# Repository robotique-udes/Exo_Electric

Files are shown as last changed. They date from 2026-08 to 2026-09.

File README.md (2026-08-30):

# Description
Ce répertoire regroupe les différents PCB de l'exosquelette au fil des compétitions. Il vise aussi à standardiser la création des schémas électriques ainsi que des PCB afin de les rendre plus lisibles et plus faciles à réviser et consulter. Les PCB avant 2026 ne suivent pas nécessairement le standard.

# Structure du repo
```
main
├── ACE2027/
│   ├── README.md
│   ├── Schéma-bloc
│   └── PCB1/
│       ├── README.md
│       ├── Schéma-bloc
│       │   ├── V1_0/
│       │   │   └── Fichiers KiCad
│       │   ├── V1_1/
│       │   │   ├── README.md
│       │   │   └── Fichiers KiCad
│       │   └── V2_0/
│       │       ├── README.md
│       │       └── Fichiers KiCad
│       └── PCB2/
│           └── (Même structure que PCB1)
└── ACE2028
    └── (Même structure que ACE 2027)
```
- Un dossier est créé pour chaque année de compétition
    - Contient un README.md décrivant le fonctionnement global du système électrique et présentant le schéma-bloc
    - Contient le schéma-bloc en image et dans son format original décrivant l'interaction entre les sous-systèmes électriques
    - Un dossier est créé par PCB
        - Contient un README.md qui explique le fonctionnement du PCB, contient les calculs et hypothèse fait pour le pcb et présente le schéma-bloc. Le README.md doit dire où se trouve le contour du pcb s'il a été fait sur ONSHAPE
        - Contient le schéma-bloc en image et dans son format original décrivant l'interaction entre les modules du PCB
            - Un dossier est fait pour chaque version du PCB.
                - La version 1_0 n'a pas besoin de README, mais les versions subséquentes devront en avoir un qui décrit les changements par rapport à la version antérieure.
                - Contient tous les fichiers KiCad

# Branches
Une branche est créée pour chaque PCB. <br>
Cette branche doit contenir le nom du PCB ainsi que sa version et le déroulement de la vie de cette branche se déroule ainsi:
1. Si le pcb est particuliairement complexe, écrire le readme et le shéma bloc qui défini ce que le PCB fait et comment il va le faire
2. Création d'une pull request vers le main afin de faire validé le fonctionnement du PCB
    - Faire les correctifs et demander à nouveau la vérification
3. Création du schéma électrique
4. Création d'une pull request vers le main afin de faire vérifier le schéma
    - Faire les correctifs et demander à nouveau la vérification
5. Création du PCB
6. Création d'une pull request vers le main afin de faire vérifier le PCB
    - Faire les correctifs et demander à nouveau la vérification
7. Suppression de la branche une fois le PCB commandé

## Convention de versions:
- V1.0  Premier prototype
- V1.X  Corrections mineures qui ne demandent pas de recommander le PCB
- VX.0  Révision majeure qui demande de recommander le PCB
- Chaque révision doit être documentée dans le README avec une explication claire des changements par rapport à la version précédente.

# Autres
**Il est très important de sauvegarder les fichiers et de fermer KiCad avant chaque commit**

# Standards à respecter
Les standards pour le schéma électrique se trouvent [ici](guideSchema.md) <br>
Les standards pour le PCB se trouvent [ici](guidePCB.md) <br>
Ces standards doivent être consultés et compris avant d'entamer le travail sur un schéma ou sur un PCB

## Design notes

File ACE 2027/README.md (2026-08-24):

# ACE 2027

Projet d’électronique et de communication pour l’exosquelette électrique.

> **Objectif principal** : faire communiquer les différents modules de l’exosquelette via un bus CAN fiable, tout en distribuant l’alimentation et en assurant les fonctions de sécurité. Le tout en prennant moins d'espace qu'avant.

## Sommaire

- [Architecture](#architecture)
- [Modules](#modules)
- [Communication](#communication)
- [Documentation du dépôt](#documentation-du-dépôt)
- [À documenter](#à-documenter)

## Architecture

Le système est organisé autour d’une carte mère (**MoBo**, *Motherboard*) qui coordonne les modules. Le **BMS** supervise les batteries et la sécurité. Les **BIMU** mesurent les mouvements, tandis que les cartes d’interface des moteurs assurent leur raccordement au réseau.

## Modules

| Module | Rôle | Éléments principaux |
| --- | --- | --- |
| **MoBo** | Carte mère et coordination de l’exosquelette | ESP32, conversion 5 V vers 3,3 V, filtrage de tension, connecteurs |
| **BMS** | Gestion des batteries et fonctions de sécurité | Fusibles, arrêt d’urgence, suivi de l’état des batteries |
| **BIMU** | Mesure et prétraitement des mouvements | IMU, traitement local des données, transmission via CAN |
| **Moteur** | Raccordement des moteurs au réseau | Carte d’interface, chaînage (*daisy chain*), connecteurs de type Ethernet |

### MoBo

La MoBo est la carte mère de l’exosquelette. Elle contient l’ESP32, qui coordonne le système, ainsi qu’une conversion 5 V vers 3,3 V, le filtrage des tensions et les connecteurs nécessaires.

### BMS

Le BMS gère les batteries, les fusibles et l’arrêt d’urgence. Il doit également communiquer avec la MoBo afin de transmettre l’état des batteries.

### BIMU

Chaque BIMU effectue localement le traitement initial des données de son ou de ses capteurs IMU, puis transmet les données préparées sur le bus CAN.

### Moteurs

Une carte d’interface est placée au niveau des moteurs. Elle facilite le chaînage des câbles et permet l’utilisation de câbles Ethernet pour le raccordement physique.

## Communication

Les modules communiquent principalement sur un bus CAN transporté par des câbles Ethernet. Le branchement général est représenté ci-dessous.

Schéma général du réseau de l’exosquelette

Détail du raccordement des modules

La liaison entre la MoBo et le BMS est particulière : elle doit fournir davantage de courant que les autres liaisons. Son raccordement est présenté ci-dessous.

Liaison entre la MoBo et le BMS

### Règles CAN à définir

Les éléments suivants doivent être précisés pour rendre l’architecture exploitable par toute l’équipe :

- débit du bus CAN et longueur maximale des câbles ;
- brochage des connecteurs et câblage exact de l’alimentation ;
- identifiants CAN attribués à chaque module ;
- format des messages, périodicité et unités des mesures ;
- terminaison du bus et emplacement des résistances ;
- comportement attendu en cas de perte de communication ou d’arrêt d’urgence.

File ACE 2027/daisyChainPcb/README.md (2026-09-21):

# PCB daisy chain

Ce PCB permet de passer les alimentations et les signaux de l'exo à travers celui-ci à la chaîne afin d'éviter les câbles superflus. Il sera sur les moteurs et permettra en même temps la communication et l'alimenation de ceux-ci.

## Objectifs
- Passer l'alimentation 48V d'un côté du PCB à l'autre
- Alimenter les moteurs
- Passer l'alimentation 5V d'un côté du PCB à l'autre
- Alimenter une puce permettant la conversion du 5V au 3.3V pour la communication I2C
- Remettre à niveau le signal I2C afin de s'assurer de sa bonne transmission
- Le rendre compatible avec l'exo 2026 et 2027
    - Être capable de passer la communication CAN tout en gardant la communication I2C au cas où elle doit être utilisé
- Se monter sur les moteurs de facon compacte et fiable
- Transmettre le signal UART (RX/TX) afin de communiquer de cette méthode avec les moteurs si c'est nécessaire (Certaines données peuvent être récuperer seulement dans un mode de communication et non l'autre)

## Conception

### Alimentation
Ce PCB doit gérer à la fois une alimentation de 48V et de 5V. Il y a deux grounds séparé. Le premier est celui de l'alimentation 48V et le deuxième est celui de l'alimentation de 5V. Le PCB a deux ground planes qui sont associés avec l'alimentation 5V. Cette décision a été prise afin de s'assurer de l'intégrité des signaux en donnant la plus grande surface de ground pour le circuit qui transporte les signaux. Ainsi, le ground lié à l'alimentation 48V est seulement connecté par des traces normales. La séparation de ces deux grounds permet aussi de s'assurer de ne pas avoir de tensions parasites qui passent par les IMU ou autre processeurs plus sensibles et évite donc de les détruire.

La communication I2C se fait à une tension de 3.3V. Il y a donc, sur le PCB, un convertisseur DC/DC qui transforme la tension de 5V vers 3.3V. Cette tension est ensuite envoyé vers les signaux I2C à travers une résistance de 1k.

### Disposition du PCB et choix de conception
Le PCB s'attache aux moteurs du côté des connecteurs de ce dernier. Il est donc important qu'il soit assez petit pour ne pas gêner aux mouvements de l'utilisateur. C'est pourquoi il n'y a pas de connecteurs pour l'alimentation et les signaux du côté du PCB. Seulement des beignes sont présents afin de souder des fils qui, eux, auront un connecteur au bout afin de se connecter aux moteurs.

Nous avons deux ground planes pour l'alimentation de 5V qui ont pleins de vias afin de bien connecter les deux planes ensemble.

Les traces qui transmettent les signaux sont le plus près possible l'un de l'autre et ont les mêmes longeurs. L'utilisation des vias a aussi été évité le plus possible.

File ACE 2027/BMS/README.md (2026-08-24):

# BMS

Carte de gestion et de distribution de l'alimentation de l'exosquelette.

Le BMS doit gérer l'arrêt d'urgence, la protection des batteries, la sélection entre deux batteries et la distribution des rails **5 V** et **48 V**. Il transmet également l'état du système au MoBo.

> **État du projet :** conception préliminaire  \
> Plusieurs valeurs et choix de composants restent à valider avec les batteries et les charges réelles.

## Objectifs

* Géré l'arrêt d'urgence de l'exosquelette
* Intégré des fuses de sécurités(une par batterie, une par jambe, une pour le circuit 5V)
* Avoir un circuit contre la reverse polarity(back current EMF)
* Une stratégie de Handshake ou autre pour ne pas shorté les batteries ensembles(mosfet de controle)
* LED pour confirmé que le circuit est alimenté(après les fuses pour connaitre l'état des fuse en même temps)
* Pouvoir géré 4A à 48V continue
* Pouvoir delivré 2.5A à 5V continue (5*200mA par BIMU et 400 mA pour le MOBO, le reste est pour le BMS) 
* Pouvoir donner le pourcentage de batterie restante
* Avoir une connection XT ??? par batterie
* Avoir une conenction Ethernet pour la connection 5V et CAN
* Avoir une connection XT30 par jambe
* Pouvoir automatiquement changé de batterie
* Avoir des lumières d'état autour des batterie

## Conception

- Seuls les ESP32 du **MoBo** et du **BMS** disposent d'une connectivité sans fil. Les deux sont inclus dans le budget de puissance, mais seul le sans-fil du MoBo sera utilisé en fonctionnement normal. La consommation **MISC** représente une estimation des pertes du PCB, des pertes de conversion, des petits composants et des LED. **LED_BMS** correspond à la puissance disponible pour d'éventuelles LED décoratives. Elle ne fait pas partie du total et sera calculée lorsque les autres besoins seront figés.

### Budget de puissance 5 V

Les estimations ci-dessous utilisent le rail 3,3 V et une marge de conversion de 20 %.

| Charge | Hypothèse | Puissance estimée |
| --- | --- | ---: |
| MoBo | `(300 mA + 100 mA MISC) x 3,3 V` | **1,32 W** |
| BIMU | `(35 mA + 100 mA MISC) x 3,3 V` | **0,45 W** |
| BMS | `(300 mA + 100 mA MISC) x 3,3 V` | **1,32 W** + `LED_BMS` |

Un rendement de **80 %** est retenu pour le convertisseur principal vers 5 V. Cette hypothèse reste volontairement prudente, car la tension de batterie peut varier fortement et le convertisseur doit couvrir une grande plage de tension d'entrée.

### Estimation

```text
P nécessaire = (1,32 W + 0,45 W + 1,32 W) / 0,80
			 = 3,87 W

I sous 5 V  = 3,87 W / 5 V
			 = 0,774 A
```

Un convertisseur **5 V / 1 A** couvrirait donc l'estimation actuelle. Cependant, le câble Ethernet envisagé avec des conducteurs de **23 AWG** est donné pour environ **0,7 A par conducteur**. Avec trois conducteurs 5 V et trois conducteurs GND, la capacité théorique atteindrait `0,7 A x 3 = 2,1 A`.

Par prudence et pour conserver une marge d'évolution, le convertisseur cible sera choisi dans une plage de **2 à 4 A**, selon les besoins confirmés et les composants disponibles. Un fusible de **2 A** en amont du câble est envisagé.

## Points à confirmer

- Référence exacte des batteries, tension minimale et tension maximale.
- Type de connecteur batterie (`XT ?`) et courant admissible réel.
- Courant de démarrage et courant continu de chaque jambe.
- Méthode de mesure de l'état de charge et précision attendue.
- Protocole du handshake de sélection de batterie et comportement en cas de défaut.
- Validation thermique du convertisseur 5 V, des MOSFET et des fusibles.
- Courant admissible du câble Ethernet utilisé pour le 5 V sur la longueur finale.

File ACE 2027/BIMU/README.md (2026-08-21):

# BIMU — IMU ESP32 + LSM6DSV16BXTR

Petit module IMU conçu autour d'un `ESP32` et du capteur inertiel `LSM6DSV16BXTR`. Il fournit des mesures d'accélération et de rotation destinées aux calculs de l'exosquelette.

## Objectif
* Communication CAN avec le reste de l'exosquelette
* Refresh rate minimal de 100Hz si possible 200Hz pour futur proof
* Précision de 1° minimum
* Consommation minimale
* Programmation par USB
* 3 DEL pour diagnostic

## Conception
Le `LSM6DSV16BXTR` propose des modes d'échantillonnage configurables, du mode basse fréquence pour économiser l'énergie jusqu'à des ODR élevés (plusieurs centaines de Hz, voire le kHz en modes haute performance selon la fiche technique). Pour la plupart des usages, un réglage entre 200 et 1000 Hz constitue un bon compromis entre réactivité et consommation. Pour des dynamiques très rapides, privilégier `SPI` et activer les modes haute fréquence.

Après étalonnage (offsets, facteurs d'échelle, compensation thermique) et filtrage (filtre complémentaire, filtre de Kalman ou AHRS), on peut viser une précision d'orientation de l'ordre de 0,1° à quelques degrés selon les conditions, la durée d'intégration et la qualité mécanique du montage. Le bruit intrinsèque du capteur est typiquement de l'ordre de quelques µg/√Hz pour l'accéléromètre et quelques mdps/√Hz pour le gyroscope ; la performance finale dépendra du calibrage et du traitement logiciel.

Trois LED facilitent le diagnostic : la LED verte indique la présence de la tension 3,3 V, la LED bleue signale la connexion/heartbeat avec la carte principale, et la LED d'erreur (rouge) s'allume en cas de problème (communication avec le capteur, auto-test ou alimentation instable). Les motifs de clignotement sont configurables dans le firmware pour différencier les types d'anomalies.

Capture d’écran 2026-08-16 130516

Alimentation et connexions : entrée 5 V (par exemple fournie par l'Ethernet/PoE) avec régulation 3,3 V sur le PCB. Le capteur communique avec l'ESP32 par `SPI`. L'ESP32 communique avec le reste de l'exosquelette via `CAN`. La puce peut être programmée via `USB-C` ou `UART`. Il a bien sûr les boutons pour BOOT et EN l'ESP-32.

Capture d’écran 2026-08-16 130627

Les résistances de terminaison CAN sont présentes sur le PCB. Il est important de respecter le côté maître du bus si celui-ci est utilisé. Pour activer la terminaison, souder C210, R211 et R212.

Capture d’écran 2026-08-16 130715

À prévoir dans le firmware : une fonction d'étalonnage, une compensation en température, le traitement des données sur l'IMU et une synchronisation via heartbeat. Il faut garder à l'esprit que le PCB ne sera pas nécessairement installé dans l'orientation prévue ; prévoir donc un réglage d'axes dans le firmware.

Il est possible de short des broches pour connecter ou isoler l'UART provenant de l'Ethernet vers l'ESP32 (utile pour communiquer avec le moteur si nécessaire).

Capture d’écran 2026-08-16 130741Capture d’écran 2026-08-16 130730

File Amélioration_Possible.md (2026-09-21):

| Idée | État | Année intégration | Description |
| --- | --- | --- | --- |
| **BIMU** | En cours | ACE2027 | Faire un IMU custom qui peut être connecté par CAN |
| **BMS QUICK SWAP** | En cours | ACE2027 | Faire un BMS qui permet de quick swap des batteries de perceuse |
| **EMG CUSTOM** | En attente | ACE2027 | Faire des emg qui permettrais de quantifier l'efficacité de l'exosquelette et peut-être de le controlé dans une prochaine année |
| **BATTERIE CUSTOM** | En cours | ACE2028 | Faire notre propre batterie avec potentiellement un BMS custom |
| **LIGHT SHOW** | En attente | ACE2027 | Faire un module LED CAN  |
| **E** | En attente | ACE20?? | Faire  |

Mobo

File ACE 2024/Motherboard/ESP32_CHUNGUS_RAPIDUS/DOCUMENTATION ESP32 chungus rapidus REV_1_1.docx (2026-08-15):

UNIVERSITÉ DE SHERBROOKE

Faculté de génie

Département de génie électrique, génie informatique et génie robotique

Documentation
ESP32 CHUNGUS RAPIDUS REV. 1.1

Groupe technique Robotique UdeS

Biogénius

Présenté aux

Membres de l’équipe Biogénius, Contrôle

Présenté par

Jacob Turcotte – turj3113

Sherbrooke – 24 Mai 2024

Table des matières

Liste des figures

Liste des tableaux

Lexique

Terme technique | Définition

Liste des symboles

Symbole | Définition

Liste des acronymes

Acronyme | Définition

# 1. Introduction

Ce document a été conçu pour vous guider à travers les différentes étapes et composants de notre système, depuis l'identification des problèmes courants jusqu'aux pistes d'amélioration futures. Vous trouverez des sections détaillées sur la connexion des différents modules, l'alimentation, et l'utilisation de périphériques I2C tels que le multiplexeur, les extensions GPIO et PWM. Nous couvrirons également l'intégration du microcontrôleur ESP32, ainsi que les solutions d'affichage à LED. Chaque partie est structurée pour offrir une compréhension claire et pratique, facilitant ainsi la mise en œuvre et le dépannage.

# 2. Problèmes connus et solutions

## Liste de problèmes

- Alimentation 3v3 qui n’allume pas
  - Si nous allons voir la documentation des MIC5504-3.3YM5 (REF), à la page 9 (REF image). Il est expliqué que la pin ENABLE doit être à HIGH (tension plus haute que 1.2V). Bien qu’il ait une résistance pull-down, il est préférable de mettre ce pin à HIGH pour assurer le bon fonctionnement de l’alimentation.

Figure 1: Page 9 documentation MIC5504

  - La REV1.1 a un saut de soudure disponible sur chacun des MIC5504 mais celui -ci va à la terre (REF image). Ainsi, l’utilisation du saut de soudure ne règle en aucun cas le problème.

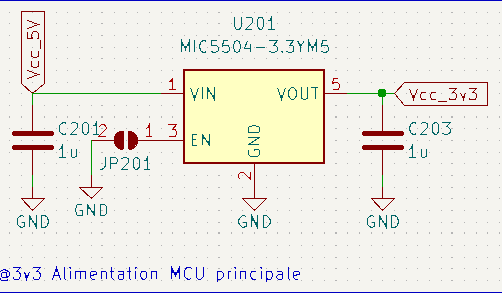
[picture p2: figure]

Figure 2: Démonstration du problème d'alimentation

- Sérigraphie à l’envers
  - La sérigraphie des connecteurs du côté gauche (connecteur pour le BNO de la hanche gauche et connecteur du MD gauche), sont tous les deux inversé de 180 degrés (REF image).

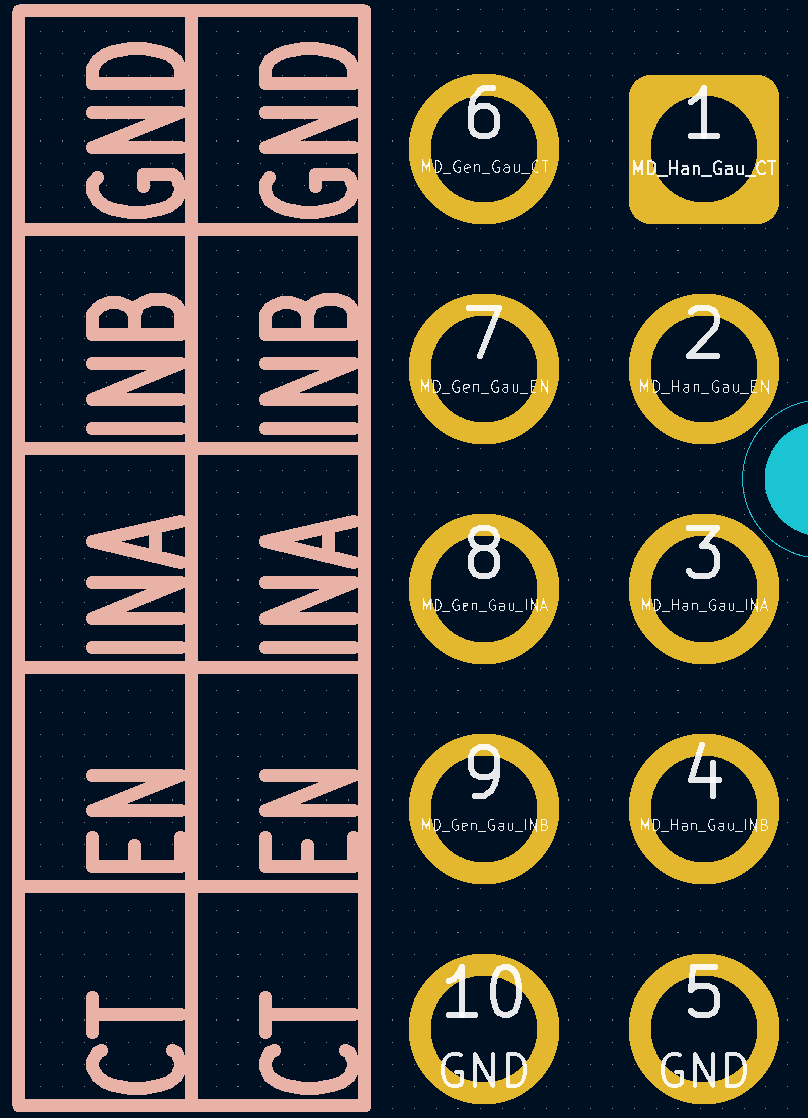
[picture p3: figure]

Figure 3: Démonstration de la mauvaise sérigraphie du connecteur pour MD gauche

- Manque le connecteur TTL pour le HMI
  - Le connecteur pour le HMI est manquant sur le PCB. Les pins à utiliser sont, GPIO17 et GPIO16. Il manque aussi les connections nécessaires pour alimenter le HMI.
- Reset des capteurs sur pin GPIO TX
  - La pin GPIO17 utilisée comme transmetteur (TX) afin de communiquer avec le HMI est déjà utilisé (REF image). Elle est connectée au signal Reset envoyé aux capteurs. Cela a été fait afin de pouvoir mettre le signal à LOW dans le code si jamais le MCU détecte une erreur venant des capteurs.

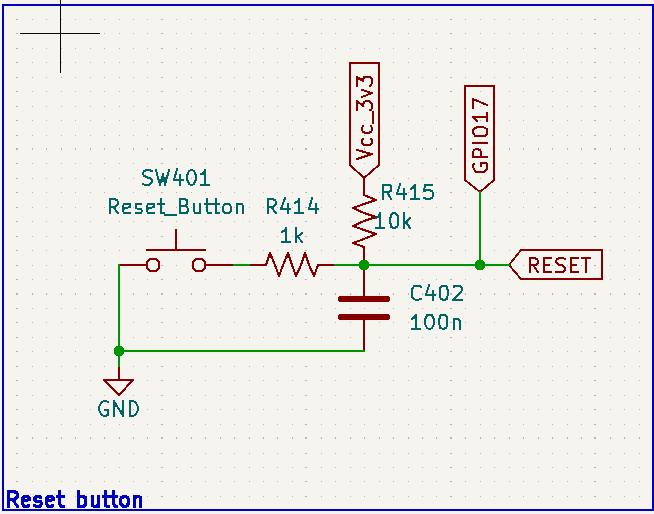
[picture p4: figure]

Figure 4: Démonstration de l'erreur RESET dans le schéma électrique

- Connection I2C sur le module PWM inversé
  - Les pins de la connexion I2C allant du MCU au PCA9685PW sont inversé. Le SDA du Esp32 est dans le SCL du module et le SCL du MCU est dans le SDA du PCA9685PW.
- PULLUP Nécessaire sur la moustache
  - Les proxims sont trop éloignés et le SCL n’a pas le temps de revenir à 3v3. Le fix est d’ajouter une PULLUP 2k sur la moustache car en ce moment c’est la pullup du BNO qui s’en occupe qui est à genre 3m.

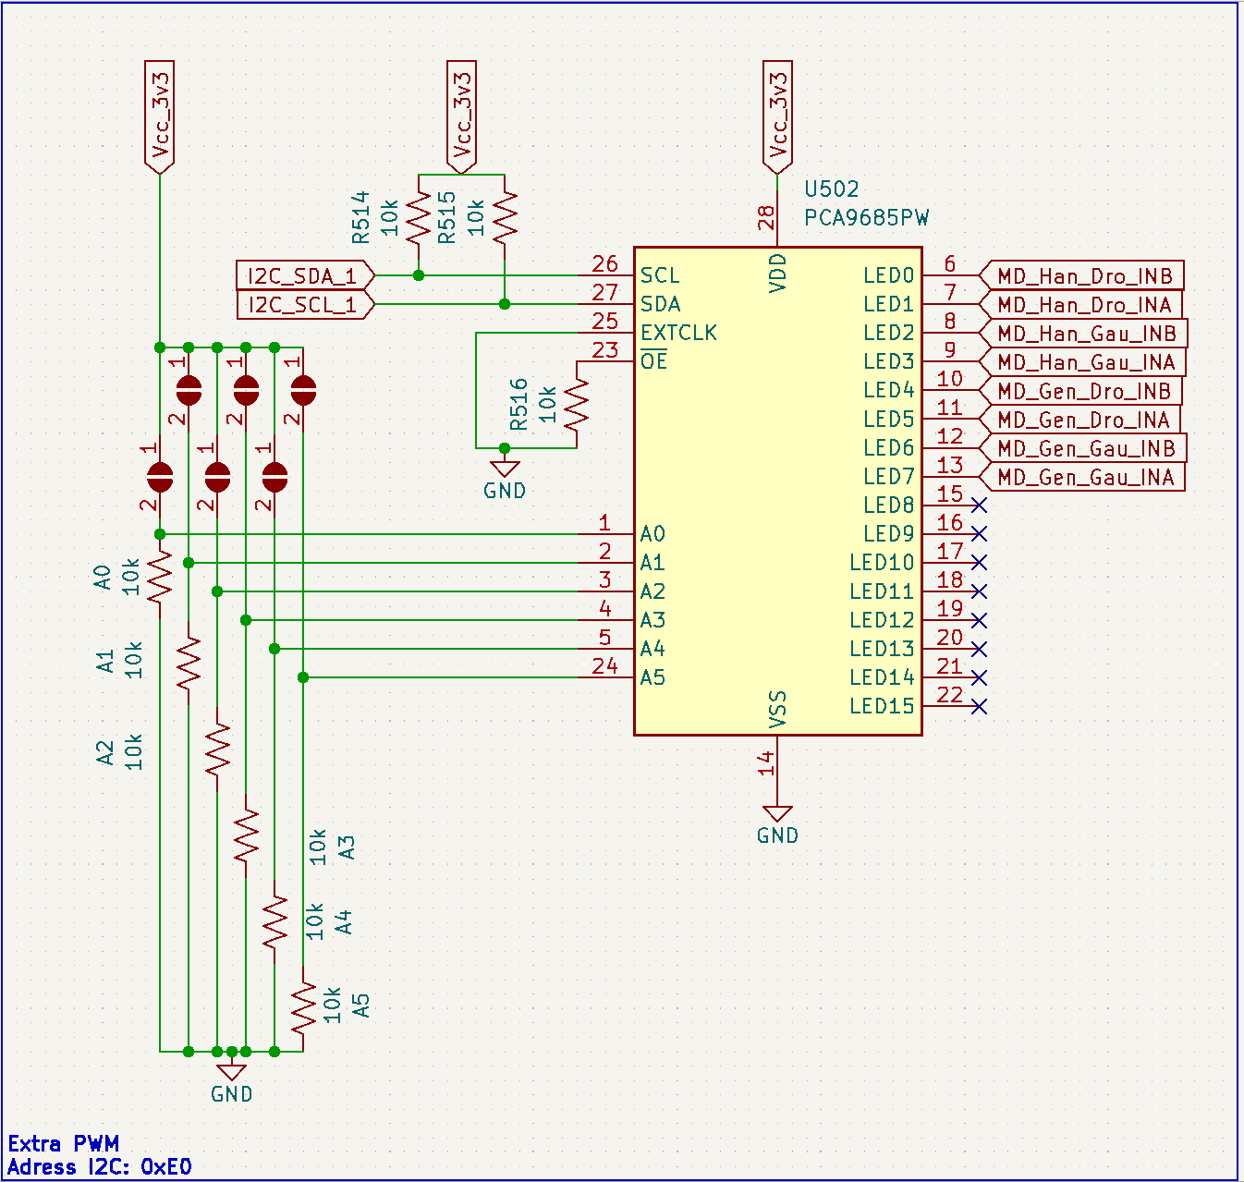
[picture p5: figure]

Figure 5: Démonstration du schéma électrique avec erreur I2C

- Connecteur du relais et du BNO dos sont trop proche
  - Les deux connecteurs sont beaucoup trop proches de l’un et l’autre. Dès que l’on branche les fils dessus, il n’est pas possible de brancher l’autre sans que celui-ci soit incliné (REF image).

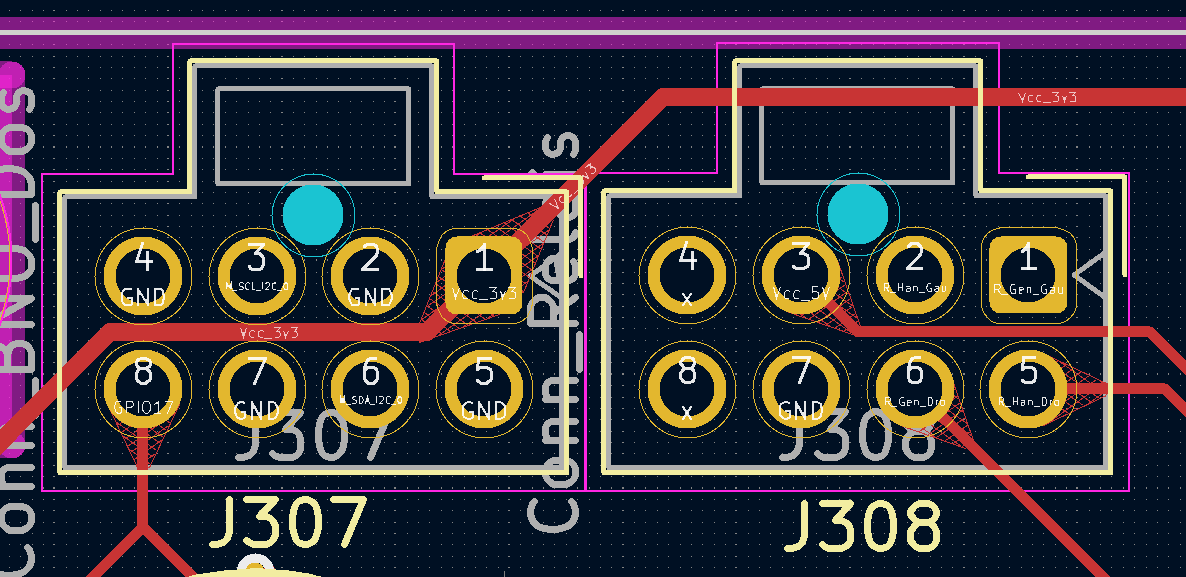
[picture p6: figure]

Figure 6: Démonstration dans le PCB editor des connecteurs trop proches

- BNO dos fait tout planter
  - Lorsque branché au PCB principale, le BNO dos fait tout planter. La communication I2C ne marche plus et aucun autre BNO est détecté.
- Pas capable de télécharger du code dans le ESP32
  - La pin GPIO12 doit être à LOW lorsque nous téléchargeons du code dans le ESP32. La pin en question est branché à l’encodeur du moteur genou droit, il se peut que la pin soit à HIGH à certains moments.

## Liste de solutions temporaires faits

- Alimentation 3v3
  - Nous avons utilisé un fil de cuivre émaillé de 4oz afin de souder les pins ENABLE au 5V entrant (REF image).

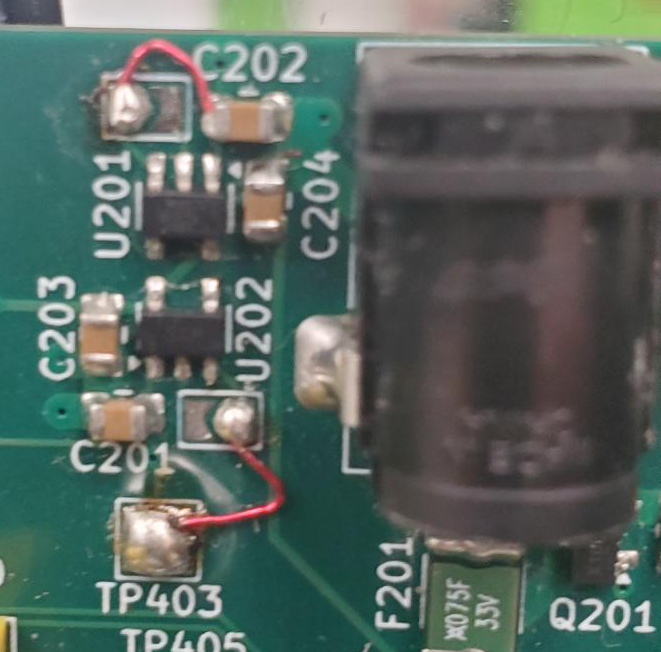
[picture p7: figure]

Figure 7: Démonstration de la solution temporaire de l'alimentation

- Sérigraphie
  - Nous avons utilisé un marqueur noir afin d’effacer la mauvaise sérigraphie et de réécrire le bon brochage (REF image).

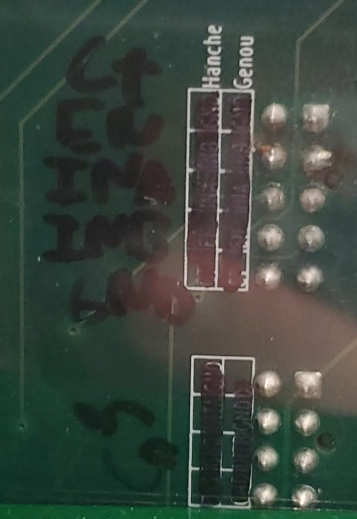
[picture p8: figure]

Figure 8: Démonstration de la sérigraphie temporaire

- Connecteur HMI
  - Nous avons soudé un connecteur Molex nano fit 2 par 2 sur les pins GPIO17 (TX), GPIO16 (RX) et nous avons utiliser les points de tests 5V et GND afin d’alimenter le HMI (REF image).

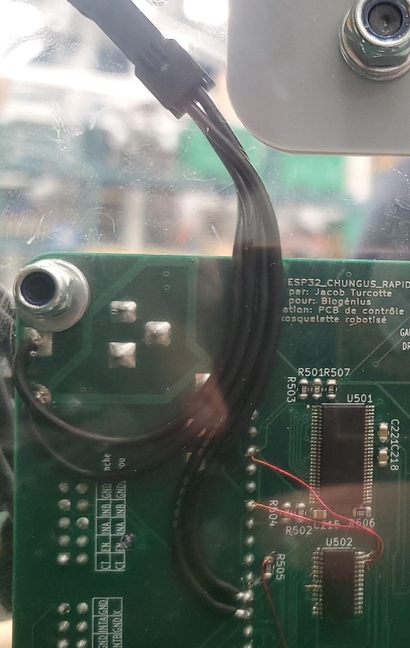
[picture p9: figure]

Figure 9: Démonstration du connecteur 2 par 2 HMI

- GPIO17
  - Nous avons gratté chaque trace RESET allant au GPIO17. Il a ensuite été nécessaire de reconnecter toutes ces traces ensemble afin de s’assurer du bon fonctionnement du bouton RESET. Nous avons utilisé un fil de cuivre émaillé de 4oz afin d’y arriver (REF image).

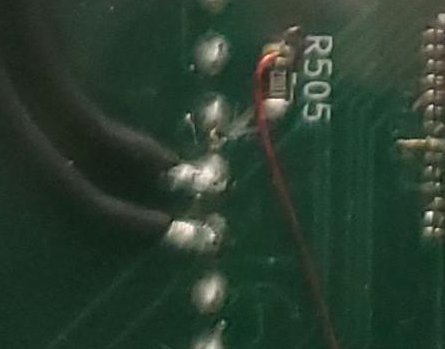
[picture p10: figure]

Figure 10: Démonstration du fixe du GPIO17

- I2C Module PWM
  - Nous avons dessoudé les pins I2C du module et nous les avons resouder correctement avec l’aide de fils de cuivre émaillé 4oz (REF image).

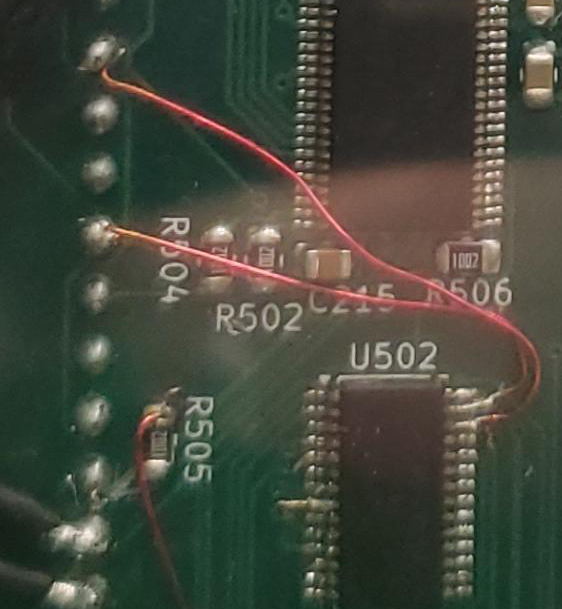
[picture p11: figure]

Figure 11: Démonstration de la reconnexion du port I2C au module PWM

- Connecteur relais et connecteur BNO dos
  - Nous avons sablé l’un des 2 connecteurs afin de laisser assez de place pour l’autre (REF image).

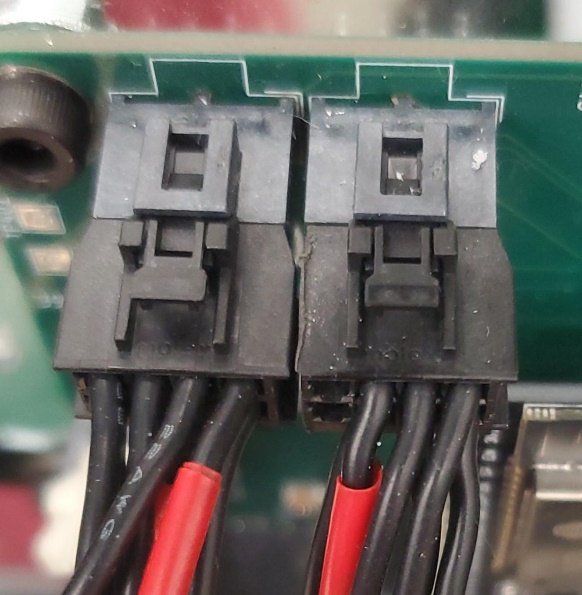
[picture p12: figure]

Figure 12: Démonstration des connecteur BNO dos et relais

- BNO dos
  - Le problème ne vient pas du PCB CHUNGUS RAPIDUS, il vient du boitier créer afin de protéger le BNO. L’une des 2 vis rattachant le boitier au frame était trop haute et causait un court-circuit entre le GND, RESET, SDA et SCL. Le fix a été de rajouter des rondelles afin d’augmenter la distance du PCB BNO et l’enveloppe. Nous avons aussi changé la vis M6 pour une vis M3.
- Télécharger du code dans le EPS32
  - La solution temporaire est simplement de faire tourner le moteur genou droit jusqu’à temps que celui-ci soit un niveau LOW.
- PULLUP nécessaire pour les moustaches
  - Nous avons soudé une 2k entre SDA et 3v3 puis SCL et 3v3. Nos signaux sont beaux à nouveau

# 3. Liste des connections

## Connections vers capteurs ou actuateurs (REF image)

- Une connexion BNO dos 2 par 4 (rouge)
- Une connexion relais 2 par 4 (vert)
- Deux connexions « Motor Drive » 2 par 5 (jaune)
- Deux connexions pour les encodeurs des hanches (bleu)
- Deux connexions aux moustaches 2 par 8 (mauve)

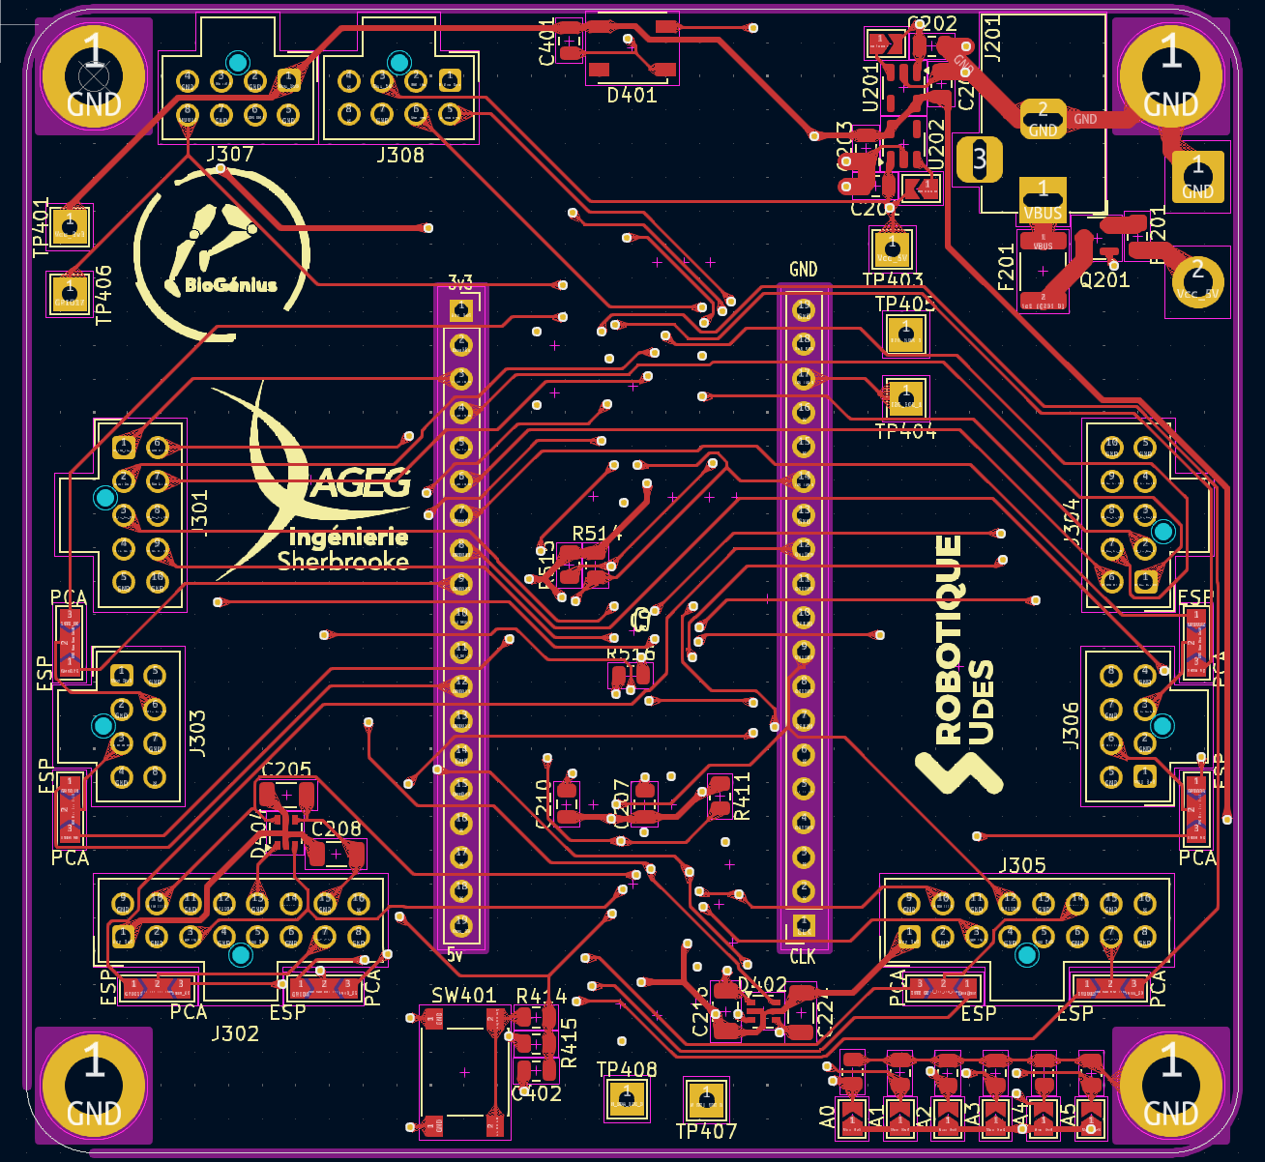
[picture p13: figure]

Figure 13: Connections capteurs/actuateurs

## Connections pour ESP32

- Se référer à la section (REF section ESP32) pour plus de détails sur le pin out. (Jaune)

Figure 14: Connexion ESP32

## Connections pour alimentation

- Il a deux façons d’alimenter le PCB
  - La première en rouge, est d’utiliser le connecteur « Barrel jack »
  - La deuxième en jaune, est de souder le GND au trou carré et le 5V au trou rond.

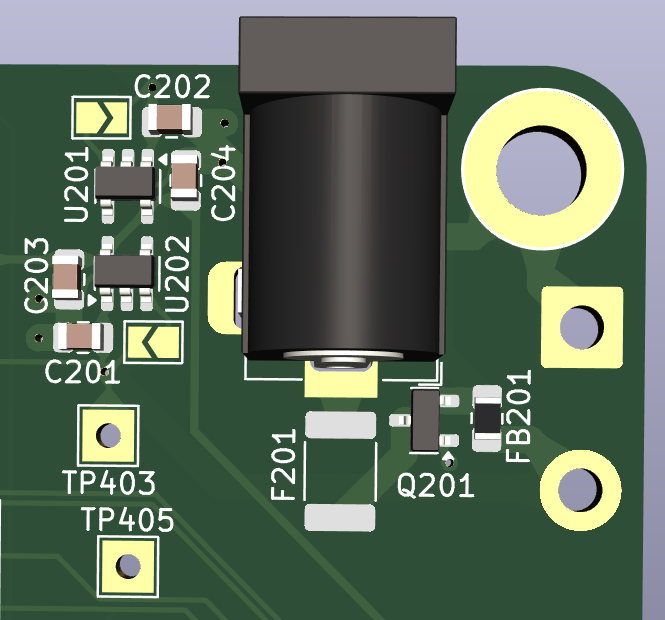
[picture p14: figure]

Figure 15: Connections alimentation

# 4. Alimentation

Il a 3 alimentation externes possible au circuit « Chungus rapidus ». Il a celle USB venant du ESP32, le « Barrel jack » et les fils que nous pouvons souder. Chacune de ces alimentations sont 5V.

Il a au total, 3 régulateurs de tension sur le circuit. Deux MIC5504-3.3YM5-TR (régulateur 3v3) et un régulateur 3v3 sur le ESP32 (AMS1117-3.3). Au total, le circuit peut alimenter 1,6A à 3v3 ce qui est plus que suffisant pour alimenter tout les circuits et capteurs (environs 750mA total).

# 5. TCA9548 (Multiplexeur I2C)

L’adresse I2C du multiplexeur est le 0x70. Le multiplexeur permet de rediriger la communication I2C d’un port vers 8 autres ports I2C. Nous avions un problème d’adresse où les BNO ont juste 2 adresses possibles. Avec 5 BNO sur l’exosquelette, on avait des erreurs de communication tout le temps. Le TCA8548 vient régler se problème. Nous utilisons présentement seulement 3 des 8 ports I2C disponibles.

Voir I 2C-scanner dans le GitHub pour plus d’information.

# 6. PCA9685 (PWM)

L’adresse I2C du PCA9685 est le 0x7C. Il permet de diminuer les pins utilisés du ESP32 et d’alléger le code. Les PWM sont utilisés afin de contrôler la vitesse et la puissance des moteurs. Au total, nous utilisons 8 des 16 pins PWM disponible sur le PCA9685.
L’adresse de celui-ci peut être changé au besoin en soudant les ponts d’étain.

Voir ESP-Motor dans le GitHub pour plus d’information.

# 7. PCA9505 (GPIO)

L’adresse I2C du PCA9505 est le 0x20. Il permet aussi de diminuer les pins utilisés du ESP32. Cependant celui-ci n’allège pas le code. Le PCA9505 est un « GPIO extender », il rajoute 40 pins GPIO à un circuit. Dans notre cas nous utilisons seulement les pins comme sortie car le protocole I2C n’est pas assez rapide pour gérer les encodeurs.
Sur les 40 pins, 17 sont utilisées. L’adresse de celui-ci peut aussi être changé au besoin.

Voir Pin_extender dans le GitHub pour plus d’information.

# 8. ESP32

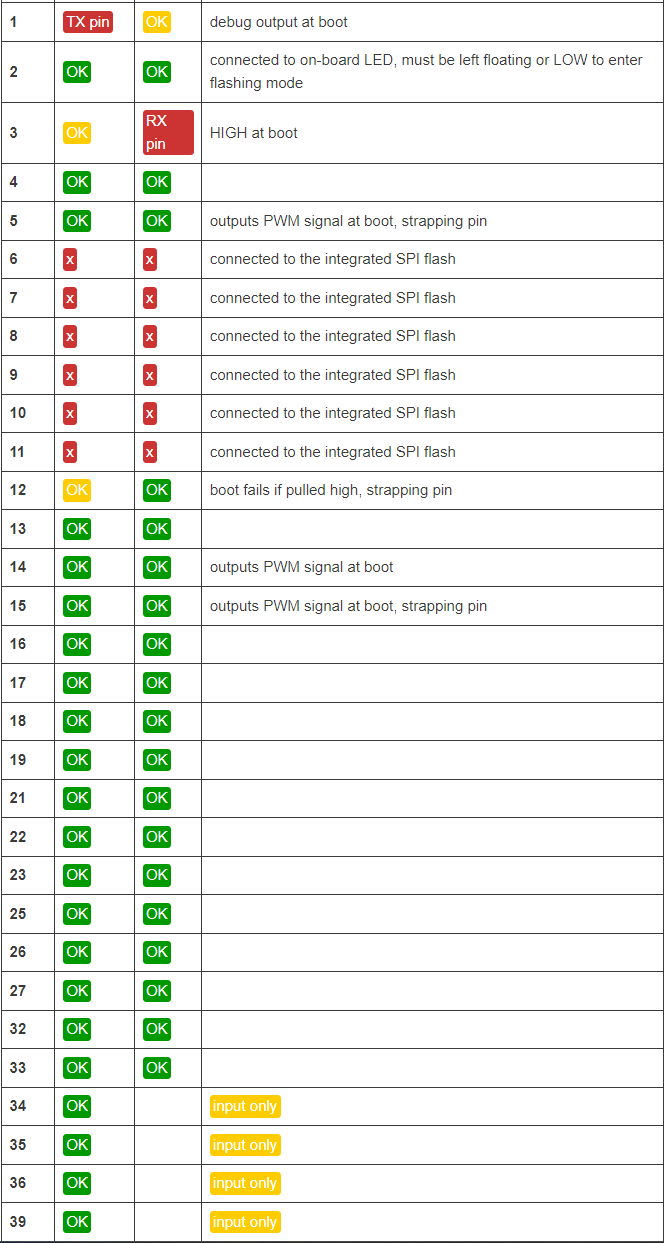
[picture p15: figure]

Figure 16: Tableau du pin out du DevBoard WROOM ESP32

Nous utilisons le ESP32 comme microcontrôleur pour sa versatilité et sa vitesse d’exécution. Son coût abordable est un gros plus aussi. Nous avons décidé d’utiliser un DevBoard afin de nous faciliter la tâche et sauver du temps pendant la conception du circuit. S’il vous plaît vous référer à la figure (REF) pour le pin out.

# 9. DEL

# 10. Points de tests

# 11. Références

There are no sources in the current document.

# Annexe A MIC5501

# Annexe B MIC5501

# Annexe C Exemple d’annexe

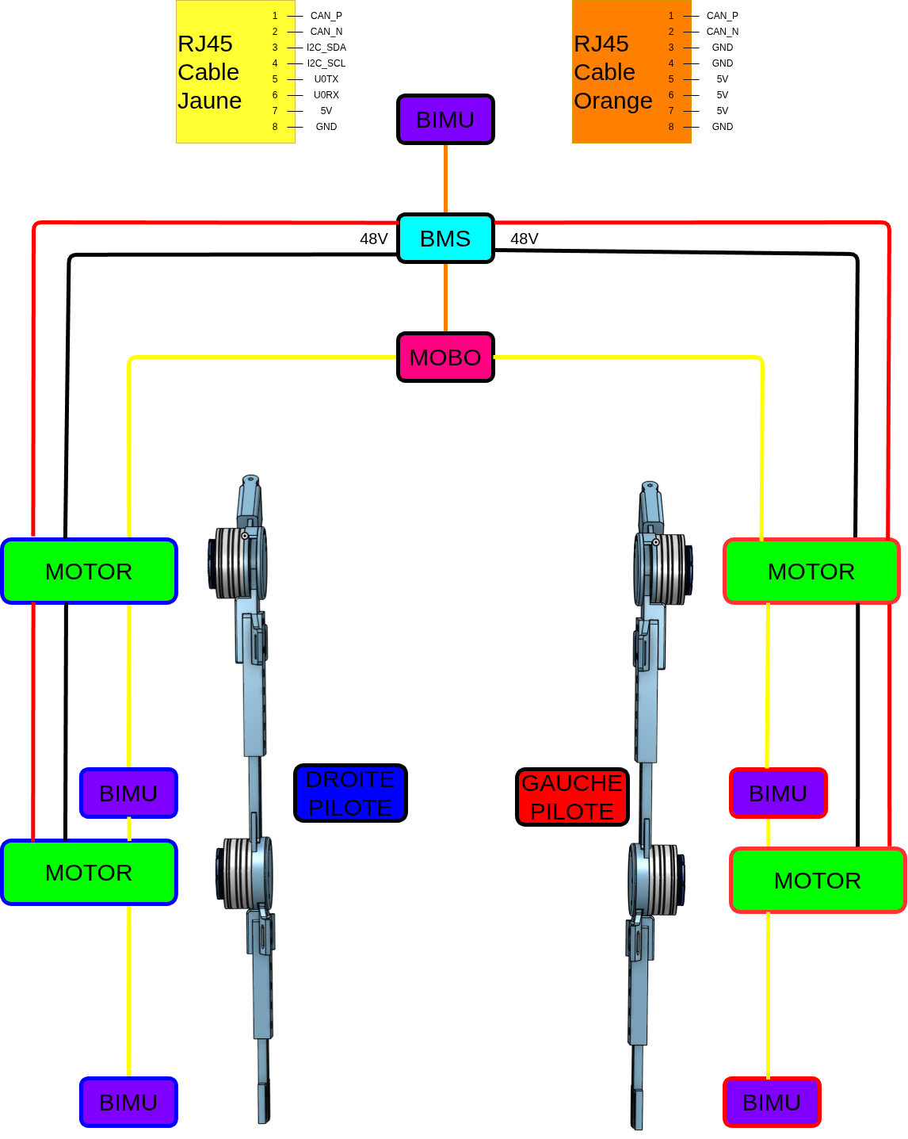
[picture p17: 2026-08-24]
ACE 2027/shemas2027.png

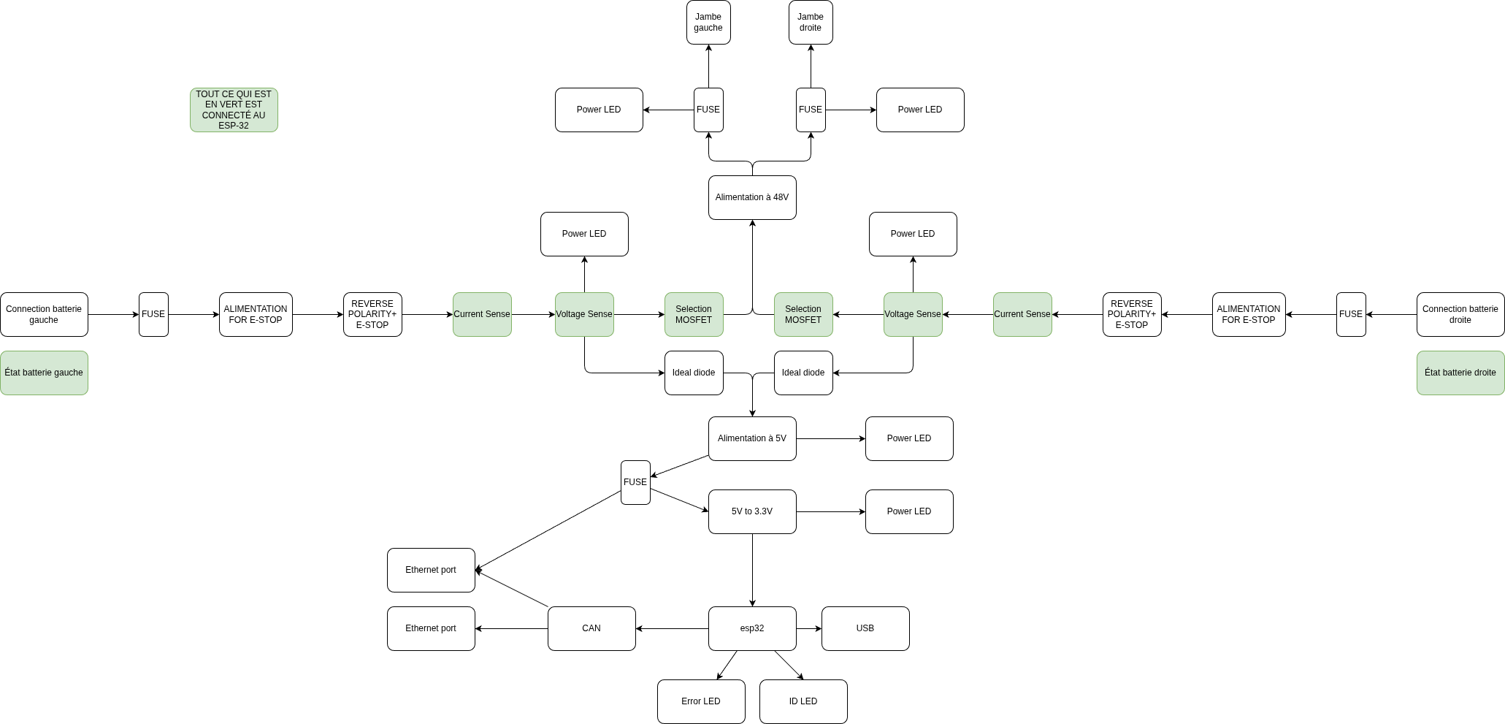
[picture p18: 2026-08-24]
ACE 2027/BMS/BMS.png

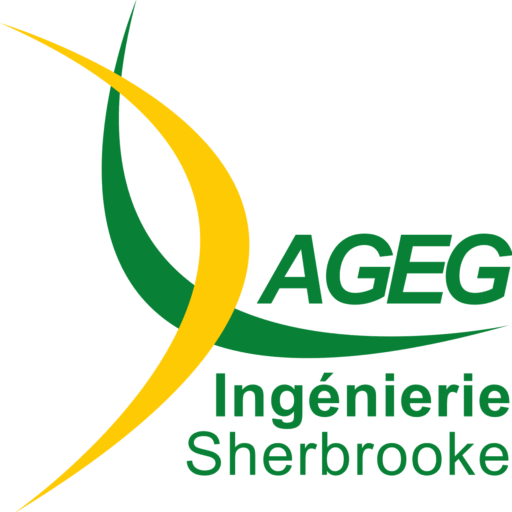
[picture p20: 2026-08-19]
Ressource/AGEG_symbol.png

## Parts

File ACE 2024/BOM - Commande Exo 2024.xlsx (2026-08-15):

Pour la nouvelle version de l'exo, on veut commander à nouveau tout le stock électrique pour faciliter l'installation sur l'exo et ne pas avoir à démonter l'ancien
 | Nom | QTY requise | En stock | Prix unitaire | Prix | Commentaire | Commandé | Lien
Filage
 | fil silicone 22 AWG | 1 |  | 37.45 | 37.45 | 100m | x | https://www.aliexpress.com/item/1005004583797315.html?curPageLogUid=I6X1n50ElxqA
 | fil silicone 14 AWG | 1 |  | 77.14 | 77.14 | 50m | x | https://www.aliexpress.com/item/1005004583797315.html?curPageLogUid=I6X1n50ElxqA
 | Nano fit 20-22 AWG crimp X | 600 |  | 0.1746 | 104.76 |  |  | https://www.digikey.com/en/products/detail/molex/1053002200/6131599
 | Nano fit 20-22 AWG crimp male X | 100 |  | 0.192 | 19.2 |  |  | https://www.digikey.com/en/products/detail/molex/2014472200/10257108
 | Male receptacle 4 X |  |  |  | 0 |  |  | https://www.digikey.ca/en/products/detail/molex/2014441104/10257078
 | XT30 Battery connector | 1 | 1 | 0 | 0 | On en vole à Rovus
 | 1-5 Connector |  |  |  | 0 |  |  | https://www.digikey.ca/en/products/detail/adafruit-industries-llc/5616/17506674?gad_source=1
 |  |  |  |  | 0
 |  |  |  |  | 0
 |  |  |  |  | 0
 |  |  |  |  | 0
Composants
 | Bouton d'urgence | 1 |  | 19.99 | 19.99 |  |  | https://www.amazon.ca/-/fr/mxuteuk-HB2-ES544-poussoirs-durgence-champignon/dp/B07R9QTBG7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
 | Boitier Fuse | 1 | 0 | 13.49 | 13.49 |  |  | https://www.amazon.ca/10-Gauge-Fuse-Holder-Inline/dp/B08BWRSPY1?hvadid=581886107970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
 | Dual DC Motor Drive DBH-12V | 2 | 0 | 34.18 | 68.36 |  |  | https://www.amazon.ca/Controller-Dual-Channel-Bridge-Driver-Module/dp/B07D2948RZ
 | DC DC relais | 1 | 0 | 16.99 | 16.99 |  |  | https://www.amazon.ca/XLX-High-Power-Converter-Adjustable-Protection/dp/B081X5YX8V?cv_ct_cx=buck+down+12v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
 | 4-Channel Relay Module | 1 | 0 | 10.99 | 10.99 |  |  | https://www.amazon.ca/SainSmart-101-70-101-4-Channel-Relay-Module/dp/B0057OC5O8?s=industrial
 | BNO085 | 8 | 5 | 35.99 | 287.92 |  |  | https://www.digikey.ca/en/products/detail/adafruit-industries-llc/4754/13426653
 | 3-Channel Distance Sensor | 4 | 1 | 39.95 | 159.8 |  |  | https://www.pololu.com/product/3412
 | Molex crimping tool | 1 | 0 | 26.99 | 26.99 |  |  | https://www.amazon.ca/IWISS-Crimping-Computer-Automotive-Metri-Pack/dp/B01M1YK5FM
 | Kit heat shrink | 1 |  | 18.99 | 18.99 |  |  | https://www.amazon.ca/-/fr/Assortiment-1200-gaines-thermor%C3%A9tractables-r%C3%A9tr%C3%A9cissement/dp/B0778D22WM
 | Pointe fer à souder studio | 3 |  |  | 0
 |  |  |  |  | 843.08
Molex nanofit
Endroits | Male Pin 2x2 | Male Pin 2x8 | Female 2x2 | Female 1x6 | Female 1x7 | Female 2x4 | Female 2x5 | Female 2x8 | PCB mount 2x4 | PCB mount 1x6 | PCB mount 1x7 | PCB mount 2x5 | PCB mount 2x8
Distance sensor X |  |  |  |  | 2 X |  |  |  |  |  | 2 X
PCB BNO 085 x |  |  |  |  |  | 5x |  |  | 5X
Fils Encodeurs X | 4X |  | 4X
Connexion Hanche x |  | 2X |  |  |  |  |  | 2X
Drive moteur x |  |  |  |  |  |  | 2X |  |  |  |  | 2X
Relais solenoide x |  |  |  | 1X |  |  |  |  |  | 1X
PCB Relais x |  |  |  |  |  |  |  | 2X | 8X |  |  |  | 2X
Main PCB x |  |  |  |  |  | 8x
 |  |  |  |  |  | 4x | 2x | 2X | 4 X |  |  | 2X | 2X

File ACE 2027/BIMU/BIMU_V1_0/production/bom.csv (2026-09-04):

Designator | Footprint | Quantity | Value | LCSC Part #
C101, C102 | 0805 | 2 | 4,7µF
C103, C104 | 1812 | 2 | 1nF
C201, C209 | 0805 | 2 | 22μF
C202, C203, C204, C205, C208, C301, C302 | 0805 | 7 | 0.1μF
C206, C207 | 0805 | 2 | 12pF
C210 | 0603 | 1 | 47nF
D101 | 0805 | 1 | POWER LED
D102, D103 | SOT-23 | 2 | BAV99
D201 | SOT23-6L | 1 | USBLC6-2SC6 | USBLC6-2SC6
D202 | 0805 | 1 | CONNECTED LED
D203 | 0805 | 1 | ERROR LED
J202 | USB_C_Receptacle_GCT_USB4105-xx-A_16P_TopMnt_Horizontal | 1 | USB_C_Receptacle_USB2.0_16P
J203, J204 | RJ45_Amphenol_54602-x08_Horizontal | 2 | RJ45
R101, R209, R210 | 0805 | 3 | 330Ω
R201, R202, R207, R208 | 0805 | 4 | 5.1KΩ
R203, R204, R205, R206 | 0402 | 4 | 0Ω
R211, R212 | 0805 | 2 | 50Ω
SW201, SW202 | SW_SPST_B3U-1000P | 2 | SW_Push
TP101 | TestPoint_Pad_1.0x1.0mm | 1 | TP_GND_IN
TP102 | TestPoint_Pad_1.0x1.0mm | 1 | TP_5V
TP103 | TestPoint_Pad_1.0x1.0mm | 1 | TP_3v3
TP201 | TestPoint_Pad_1.0x1.0mm | 1 | TP_CAN_P
TP202 | TestPoint_Pad_1.0x1.0mm | 1 | TP_CAN_N
U101 | SOT-223-3_TabPin2 | 1 | AP7361C-33E
U201 | QFN-32-1EP_5x5mm_P0.5mm_EP3.45x3.45mm | 1 | ESP32-C3
U202 | SOIC-8_3.9x4.9mm_P1.27mm | 1 | SN65HVD232DR
U301 | LGA-14_3x2.5mm_P0.5mm_LayoutBorder3x4y | 1 | LSM6DSV16BXTR
Y201 | Crystal_SMD_2016-4Pin_2.0x1.6mm | 1 | ABM8-40.000MHZ-10-D1G-T

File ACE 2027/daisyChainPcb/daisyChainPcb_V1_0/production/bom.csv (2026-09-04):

Designator | Footprint | Quantity | Value | LCSC Part #
C101, C102 | 0805 | 2 | 4.7uF
J201 | motorPads | 1 | Pads
J202, J203 | AMASS_XT30PW-M_1x02_P2.50mm_Horizontal | 2 | XT30
J204 | CAN_pads | 1 | Pads
J205 | UART_pads | 1 | Pads
J206, J207 | RJ45_Amphenol_54602-x08_Horizontal | 2 | RJ45
R201, R202 | 0805 | 2 | 1kΩ
TP201 | TestPoint_Pad_D2.0mm | 1 | CAN_P_TP
TP202 | TestPoint_Pad_D2.0mm | 1 | SDA_TP
TP203 | TestPoint_Pad_D2.0mm | 1 | CAN_N_TP
TP204 | TestPoint_Pad_D2.0mm | 1 | SCL_TP
TP205 | TestPoint_Pad_D2.0mm | 1 | TX_TP
TP206 | TestPoint_Pad_D2.0mm | 1 | 5V_TP
TP207 | TestPoint_Pad_D2.0mm | 1 | RX_TP
TP208 | TestPoint_Pad_D2.0mm | 1 | GND_TP
TP209 | TestPoint_Pad_D2.0mm | 1 | 48V_TP
TP210 | TestPoint_Pad_D2.0mm | 1 | Power_GND_TP
TP211 | TestPoint_Pad_D2.0mm | 1 | 3V3_TP
U101 | SOT223_DIO-L | 1 | AP7361C-33E-13

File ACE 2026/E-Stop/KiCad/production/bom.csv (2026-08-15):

Designator | Footprint | Quantity | Value | LCSC Part #
C1, C3, CBOOT1 | 0805 | 3 | 0.1uF
C2 | 0805 | 1 | Cbypass
C4 | 2220 | 1 | 4.7uF
COUT1, COUT2 | 1210 | 2 | 22uF
D1 | 0603 | 1 | Shottky
E-STOP | JST_EH_B2B-EH-A_1x02_P2.50mm_Vertical | 1 | E-Stop button
ESP-32 | JST_EH_B4B-EH-A_1x04_P2.50mm_Vertical | 1 | ESP32
F1 | 3557-15_KEY | 1 | Fuse 1A
F2 | 40A fuse holder | 1 | Fuse 40A
F3, F4, F5, F6 | 40A fuse holder | 4 | Fuse 15A
J2 | AMASS_XT30U-F_1x02_P5.0mm_Vertical | 1 | Motor1
J3 | AMASS_XT30U-F_1x02_P5.0mm_Vertical | 1 | Motor2
J4 | AMASS_XT30U-F_1x02_P5.0mm_Vertical | 1 | Motor3
J5 | AMASS_XT30U-F_1x02_P5.0mm_Vertical | 1 | Motor4
J6 | AMASS_XT60-M_1x02_P7.20mm_Vertical | 1 | Battery connections
J7 | AMASS_XT60-M_1x02_P7.20mm_Vertical | 1 | Relay contact
K2 | RELAY_G6L-1P_DC12 | 1 | Restart button relay
LOUT1 | L_Bourns_SRR1260 | 1 | 68uH
R1 | 2512 | 1 | 1m
R2 | 0805 | 1 | 191k
R3 | 0805 | 1 | 10k
R4 | 0805 | 1 | 100
RELAY CONTROL | JST_EH_B2B-EH-A_1x02_P2.50mm_Vertical | 1 | Relay control
RFBB1 | 0805 | 1 | 7.15k
RFBT1 | 0805 | 1 | 100k
S1 | SW_D6R90_F1_LFS | 1 | D6R90_F1_LFS
TP1, TP2, TP3, TP4, TP5 | TestPoint_Pad_D4.0mm | 5 | 1.0mm
U1 | SOT95P280X145-6N | 1 | LMR51610XDBVR
U3 | TSSOP-8_4.4x3mm_P0.65mm | 1 | INA240A2PW

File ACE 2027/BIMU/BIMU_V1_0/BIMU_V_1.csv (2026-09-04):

Reference | Qty | Value | DNP | Footprint | Datasheet | Digi-Key_PN
C101,C102 | 10 | 4,7µF |  | Capacitor_SMD:C_0805_2012Metric_Pad1.18x1.45mm_HandSolder |  | 1276-2970-1-ND
C103,C104 | 10 | 1nF |  | Capacitor_SMD:C_1812_4532Metric_Pad1.57x3.40mm_HandSolder |  | 399-C1812C104MDRACTUCT-ND
C201,C209 | 10 | 22μF |  | Capacitor_SMD:C_0805_2012Metric_Pad1.18x1.45mm_HandSolder |  | 1276-6501-1-ND
C202,C203,C204,C205,C208,C301,C302 | 35 | 0.1μF |  | Capacitor_SMD:C_0805_2012Metric_Pad1.18x1.45mm_HandSolder |  | 399-C0805C104K5RACTUCT-ND
C206,C207 | 10 | 12pF |  | Capacitor_SMD:C_0805_2012Metric_Pad1.18x1.45mm_HandSolder |  | 399-C0805C120J8HACTUCT-ND
C210 | 5 | 47nF |  | Capacitor_SMD:C_0603_1608Metric_Pad1.08x0.95mm_HandSolder |  | 1276-2960-1-ND
D101 | 5 | POWER LED |  | LED_SMD:LED_0805_2012Metric_Pad1.15x1.40mm_HandSolder |  | 1516-QBLP631-IG5CT-ND
D102,D103 | 10 | BAV99 |  | Package_TO_SOT_SMD:SOT-23 | https://assets.nexperia.com/documents/data-sheet/BAV99_SER.pdf | 1655-BAV99CT-ND
D201 | 5 | USBLC6-2SC6 |  | BIMU:SOT23-6L | https://www.umw-ic.com/static/pdf/b2c190f0a00a742e1ffd3347f22dc112.pdf | 4518-USBLC6-2SC6CT-ND
D202 | 5 | CONNECTED LED |  | LED_SMD:LED_0805_2012Metric_Pad1.15x1.40mm_HandSolder |  | 1516-QBLP631-IB5CT-ND
D203 | 5 | ERROR LED |  | LED_SMD:LED_0805_2012Metric_Pad1.15x1.40mm_HandSolder |  | 1516-QBLP631-R5-2897CT-ND
J202 | 5 | USB_C_Receptacle_USB2.0_16P |  | Connector_USB:USB_C_Receptacle_GCT_USB4105-xx-A_16P_TopMnt_Horizontal | https://www.usb.org/sites/default/files/documents/usb_type-c.zip | 2073-USB4105-GF-ACT-ND
J203,J204 | 10 | RJ45 |  | Connector_RJ:RJ45_Amphenol_54602-x08_Horizontal |  | 609-1046-ND
R101,R209,R210 | 15 | 330Ω |  | Resistor_SMD:R_0805_2012Metric_Pad1.20x1.40mm_HandSolder |  | 541-4168-1-ND
R201,R202,R207,R208 | 20 | 5.1KΩ |  | Resistor_SMD:R_0805_2012Metric_Pad1.20x1.40mm_HandSolder |  | 541-CRCW08055K10FKEACCT-ND
R211,R212 | 10 | 50Ω |  | Resistor_SMD:R_0805_2012Metric_Pad1.20x1.40mm_HandSolder |  | 541-CRCW080550R0FKTACT-ND
SW201,SW202 | 10 | SW_Push |  | Button_Switch_SMD:SW_SPST_B3U-1000P |  | SW1021CT-ND
U101 | 5 | AP7361C-33E |  | Package_TO_SOT_SMD:SOT-223-3_TabPin2 | https://www.diodes.com/assets/Datasheets/AP7361C.pdf | AP7361C-33E-13DICT-ND
U201 | 5 | ESP32-C3 |  | Package_DFN_QFN:QFN-32-1EP_5x5mm_P0.5mm_EP3.45x3.45mm | https://www.espressif.com/sites/default/files/documentation/esp32-c3_datasheet_en.pdf | 1904-ESP32-C3FH4CT-ND
U202 | 5 | SN65HVD232DR |  | Package_SO:SOIC-8_3.9x4.9mm_P1.27mm | https://www.ti.com/general/docs/suppproductinfo.tsp?distId=10 | 296-26344-1-ND
U301 | 5 | LSM6DSV16BXTR |  | Package_LGA:LGA-14_3x2.5mm_P0.5mm_LayoutBorder3x4y | https://www.st.com/content/ccc/resource/technical/document/datasheet/group3/fe/cf/21/3f/ed/a7/43/1c/DM00803257/files/DM00803257.pdf/jcr:content/translations/e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 | 497-LSM6DSV16BXTRCT-ND
Y201 | 5 | ABM8-40.000MHZ-10-D1G-T |  | Crystal:Crystal_SMD_2016-4Pin_2.0x1.6mm |  | 535-14997-1-ND

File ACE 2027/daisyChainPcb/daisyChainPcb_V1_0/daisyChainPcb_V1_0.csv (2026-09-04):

Reference | Qty | Value | DNP | Footprint | Datasheet | Digi-Key_PN
C101,C102 | 2 | 4.7uF |  | Capacitor_SMD:C_0805_2012Metric_Pad1.18x1.45mm_HandSolder |  | 490-12394-1-ND
J201 | 1 | Pads |  | daisyChain_Custom:motorPads
J202,J203 | 2 | XT30 |  | Connector_AMASS:AMASS_XT30PW-M_1x02_P2.50mm_Horizontal | https://mm.digikey.com/Volume0/opasdata/d220001/medias/docus/745/FIT0586_Web.pdf
J204 | 1 | Pads |  | daisyChain_Custom:CAN_pads
J205 | 1 | Pads |  | daisyChain_Custom:UART_pads
J206,J207 | 2 | RJ45 |  | Connector_RJ:RJ45_Amphenol_54602-x08_Horizontal | https://www.waldom.com/upload/parts/datasheets/mf-fci/fci-54602-908lf.pdf | 609-1046-ND
R201,R202 | 2 | 1kΩ |  | Resistor_SMD:R_0805_2012Metric_Pad1.20x1.40mm_HandSolder |  | 541-1.00KCCT-ND
TP201 | 1 | CAN_P_TP |  | TestPoint:TestPoint_Pad_D2.0mm
TP202 | 1 | SDA_TP |  | TestPoint:TestPoint_Pad_D2.0mm
TP203 | 1 | CAN_N_TP |  | TestPoint:TestPoint_Pad_D2.0mm
TP204 | 1 | SCL_TP |  | TestPoint:TestPoint_Pad_D2.0mm
TP205 | 1 | TX_TP |  | TestPoint:TestPoint_Pad_D2.0mm
TP206 | 1 | 5V_TP |  | TestPoint:TestPoint_Pad_D2.0mm
TP207 | 1 | RX_TP |  | TestPoint:TestPoint_Pad_D2.0mm
TP208 | 1 | GND_TP |  | TestPoint:TestPoint_Pad_D2.0mm
TP209 | 1 | 48V_TP |  | TestPoint:TestPoint_Pad_D2.0mm
TP210 | 1 | Power_GND_TP |  | TestPoint:TestPoint_Pad_D2.0mm
TP211 | 1 | 3V3_TP |  | TestPoint:TestPoint_Pad_D2.0mm
U101 | 1 | AP7361C-33E-13 |  | daisyChain_Custom:SOT223_DIO-L | https://www.diodes.com/assets/Datasheets/AP7361C.pdf

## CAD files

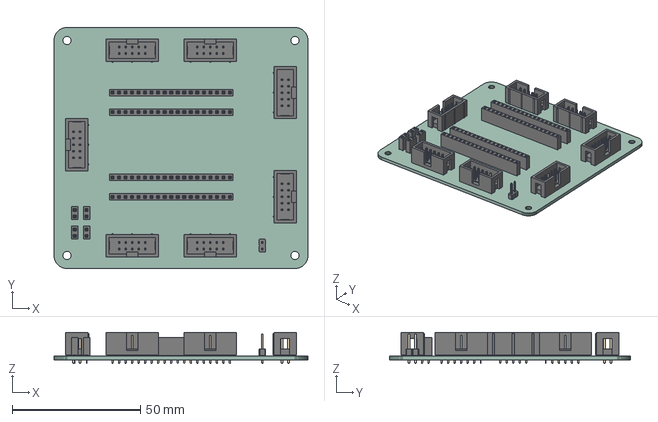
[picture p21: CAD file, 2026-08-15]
ACE 2023/PCB_BioGenius.step
99.1 x 94.0 x 12.2 mm
PCB

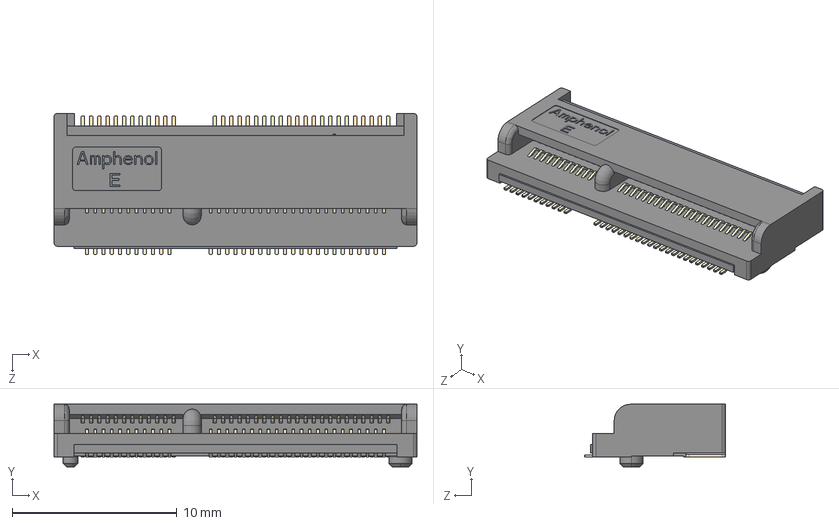
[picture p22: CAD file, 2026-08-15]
ACE 2025/SoM/Composantes_custom/MDT320E01001/MDT320E01001.step
22.0 x 3.80 x 8.55 mm

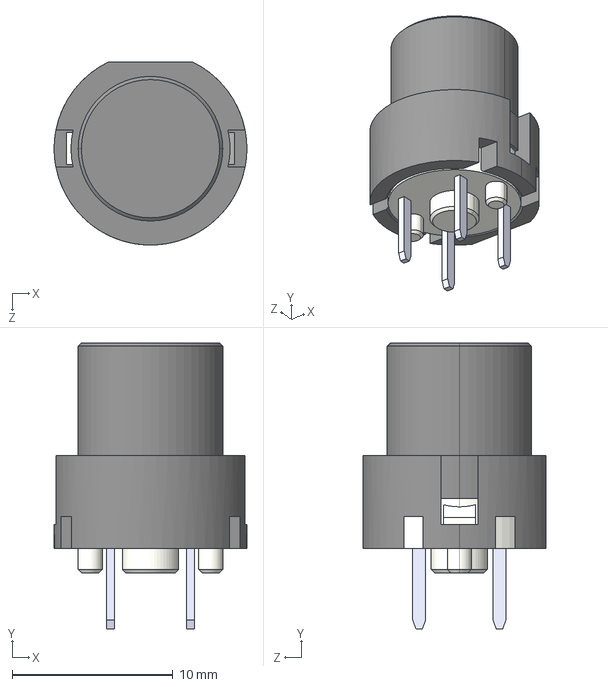
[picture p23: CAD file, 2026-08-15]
ACE 2026/E-Stop/KiCad/D6R90_F1_LFS/D6R90_F1_LFS.step
12.0 x 17.8 x 11.4 mm

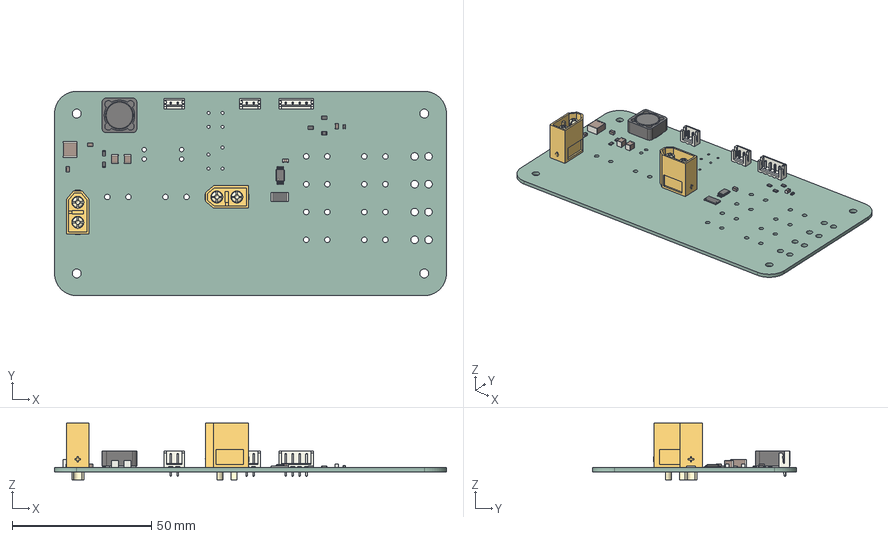
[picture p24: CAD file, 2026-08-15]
ACE 2026/E-Stop/KiCad/eStop.step
141.0 x 73.5 x 20.5 mm
C_0805_2012Metric x 4
TSSOP-8_4.4x3mm_P0.65mm
R_2512_6332Metric
AMASS_XT60-M_1x02_P7.2mm_Vertical x 2
L_Bourns_SRR1260
C_2220_5750Metric
R_0805_2012Metric x 5
C_1210_3225Metric x 2
JST_EH_B4B-EH-A_1x04_P2.50mm_Vertical
JST_EH_B2B-EH-A_1x02_P2.50mm_Vertical x 2
D_0603_1608Metric
eStop_PCB

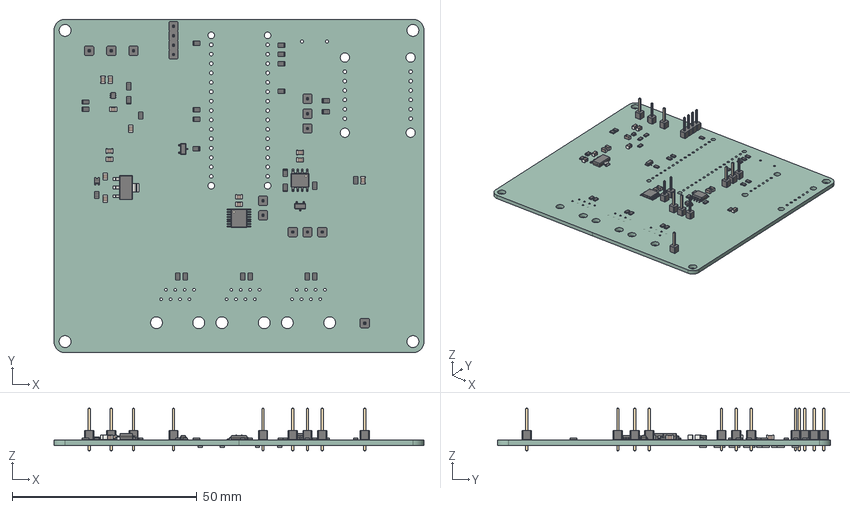
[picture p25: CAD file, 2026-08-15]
ACE 2026/Motherboard/MoBo_V2-1/MoBo_V2-1.step
100.0 x 90.1 x 11.5 mm
PinHeader_1x01_P2.54mm_Vertical x 12
R_0805_2012Metric x 37
C_0805_2012Metric x 13
D_0805_2012Metric
PinHeader_1x04_P2.54mm_Vertical
SOIC-8_3.9x4.9mm_P1.27mm
TSSOP-16_4.4x5mm_P0.65mm
SOT-23
SOT-563
SOT-23-3
Fuse_0805_2012Metric
SOT-223
MoBo_V2-1_PCB

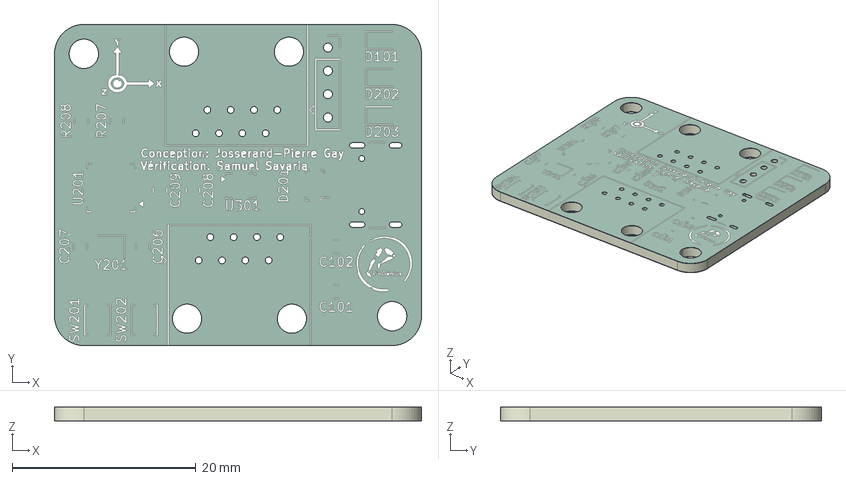
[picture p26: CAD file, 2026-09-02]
ACE 2027/BIMU/BIMU_V1_0/BIMU_V_1.step
40.0 x 35.0 x 1.66 mm
BIMU_V_1-unsaved-export-f5AWbN_silkscreen x 2
BIMU_V_1-unsaved-export-f5AWbN_soldermask x 2
BIMU_V_1-unsaved-export-f5AWbN_PCB

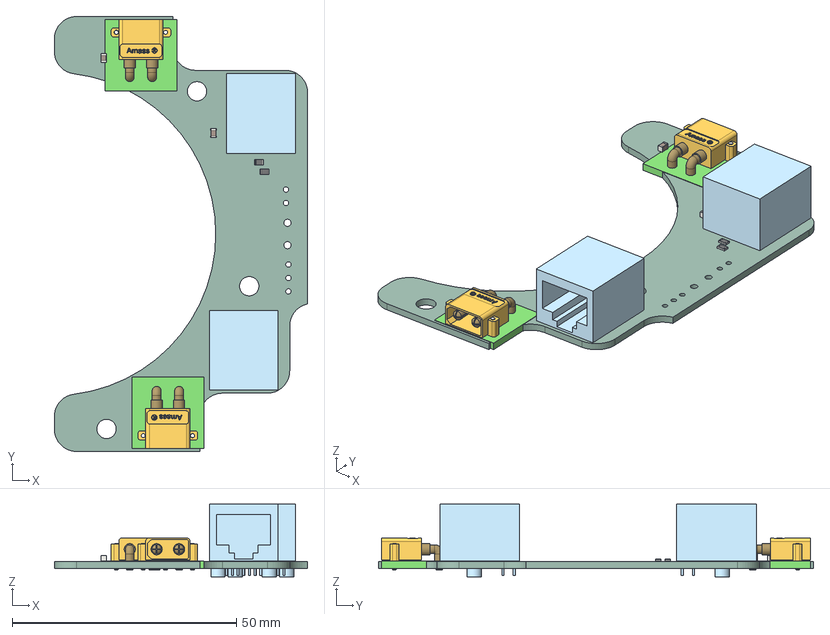
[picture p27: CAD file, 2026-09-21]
ACE 2027/daisyChainPcb/daisyChainPcb_V1_0/daisyChainPcb_V1_0.step
56.5 x 97.0 x 16.2 mm
R_0805_2012Metric x 2
C_0805_2012Metric x 2
PCB_for_XT30PW-M x 2
XT30PW-M_base x 2
Pin_M_001 x 4
fixture_003 x 4
daisyChainPcb_V1_0-unsaved-export-i1dy1g_PCB

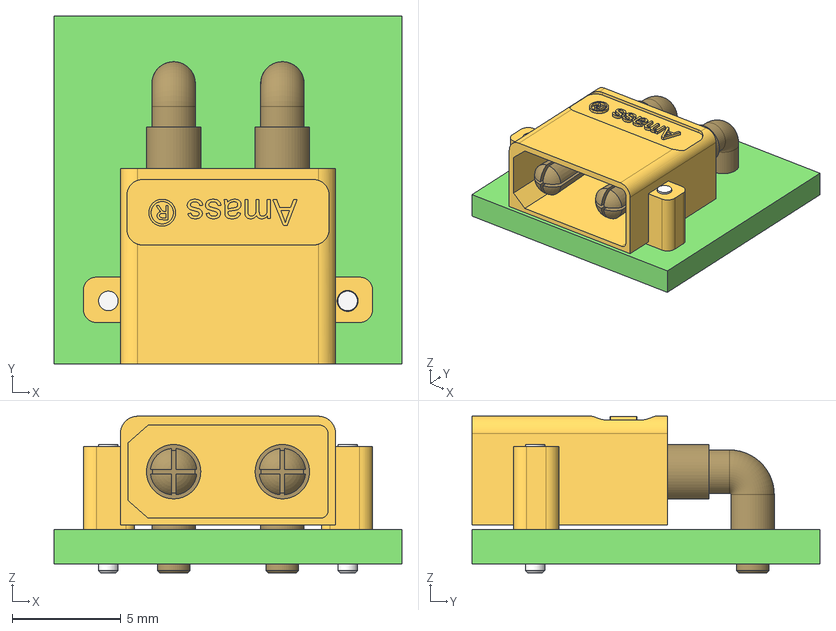
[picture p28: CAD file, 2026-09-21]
ACE 2027/daisyChainPcb/daisyChainPcb_V1_0/XT30PW-M.step
16.0 x 16.0 x 7.20 mm
PCB_for_XT30PW-M
XT30PW-M_base
Pin_M_001 x 2
fixture_003 x 2

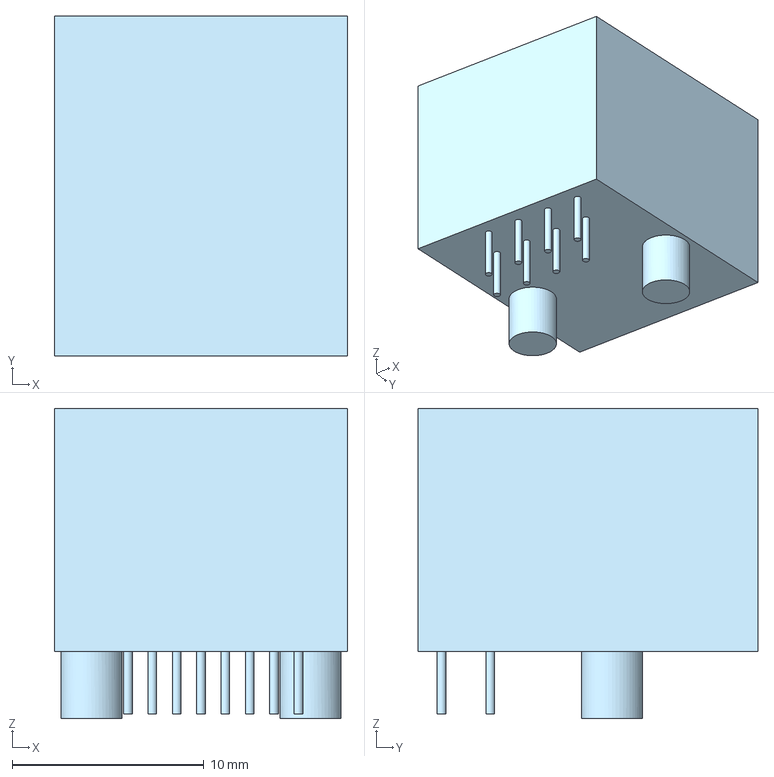
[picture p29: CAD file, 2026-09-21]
ACE 2027/daisyChainPcb/daisyChainPcb_V1_0/Port ethernet.step
15.3 x 17.7 x 16.2 mm

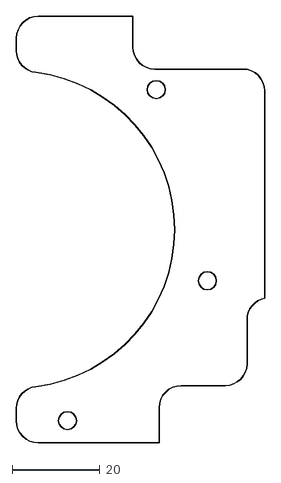
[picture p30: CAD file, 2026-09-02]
ACE 2027/daisyChainPcb/daisyChainPcb_V1_0/PCB_OUTLINE.dxf
56.5 x 97.0

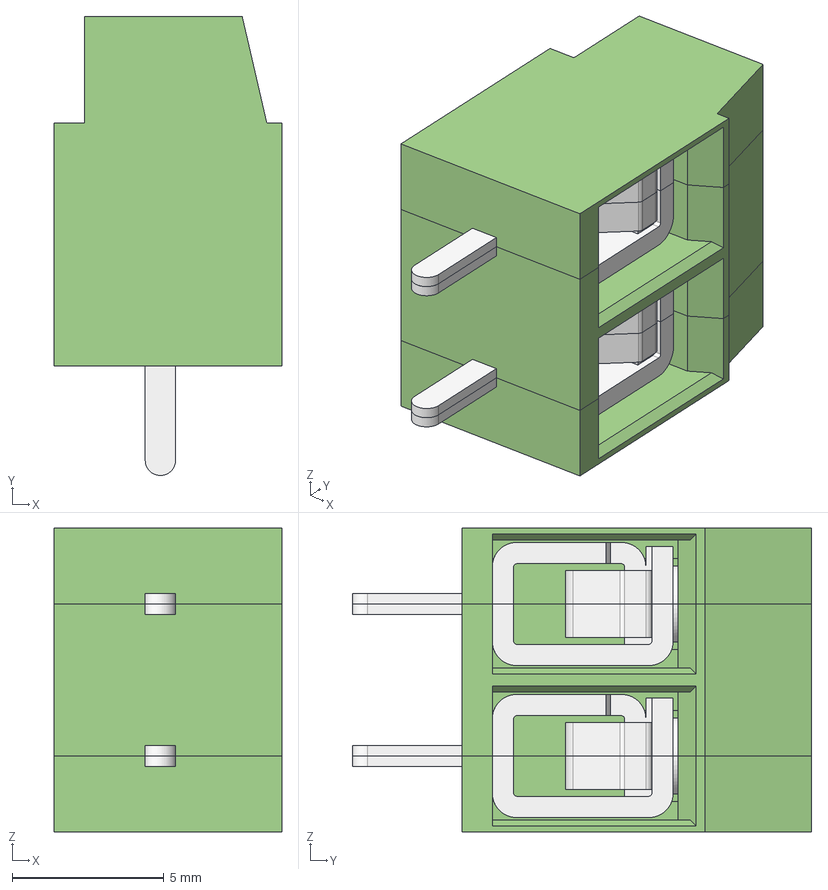
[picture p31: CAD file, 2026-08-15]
ACE 2026/E-Stop/KiCad/691137710002/691137710002.step
7.50 x 15.1 x 10.0 mm
MRT12P5_SX
MRT12P5_CNT
MRT12P5_DX

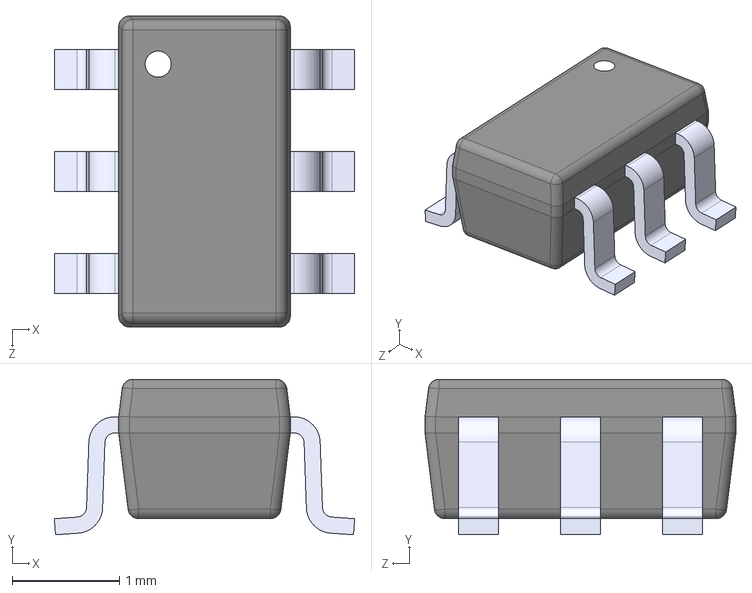
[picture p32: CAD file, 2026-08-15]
ACE 2026/E-Stop/KiCad/LMR51610XDBVR/LMR51610XDBVR.step
2.80 x 1.45 x 2.90 mm

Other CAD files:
ACE 2026/Motherboard/MoBo_V2-1/MoBo_V2-1.stl
ACE 2027/BIMU/BIMU_V1_0/BIMU_V_1.stl

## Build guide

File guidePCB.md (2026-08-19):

# Création d'un PCB

Les sections sont placées dans l'ordre dans lequel elles devraient être faites. Ne changez pas trop les réglages par défaut de KiCad : les valeurs proposées sont généralement adaptées.

> **À garder en tête**
> - Pensez à la fabrication, à l'assemblage et au débogage dès le début.
> - Limitez les changements de dernière minute : ils compliquent la validation du PCB.

## 1. Contour (*Edge Cuts*)

Il est recommandé de faire le contour sur Onshape afin d'obtenir une meilleure forme, plus simple à mettre à jour.

- N'oubliez pas d'inclure les trous de vis et les autres méthodes de fixation. L'équipe structure vous en remerciera.
- Limitez la taille à **10 cm × 10 cm**, car les coûts augmentent rapidement au-delà de cette dimension.

## 2. Placement des composants

Suivez cet ordre de priorité :

1. Placez les connecteurs et les éléments accessibles à l'utilisateur (LED, boutons, etc.) afin qu'ils soient facilement accessibles et logiquement disposés.
2. Placez les composants importants ou ayant des exigences complexes. Par exemple, un ESP32 est connecté à plusieurs éléments : une position centrale est donc utile. Un IMU doit être éloigné des sources électromagnétiques.
3. Placez les composants dont le positionnement est critique. Les condensateurs de découplage doivent notamment être proches des puces qu'ils servent.
4. Si le PCB présente un enjeu thermique, éloignez les composants qui chauffent. Pensez également à l'espace nécessaire pour souder le PCB.

> **Vérification mécanique**
> Pensez à la hauteur des composants lors de leur placement et vérifiez qu'ils ne gênent pas l'intégration finale.

## 3. Tracé des pistes

- Essayez de rester sur **deux couches** si possible.
- Tracez les pistes en priorisant les pistes différentielles et celles qui doivent être particulièrement courtes. Pour les pistes différentielles, limitez l'écart entre les deux pistes à **1 mm maximum**.

<p align="center">Exemple de tracé de pistes différentielles</p>

Tracez ensuite les pistes de puissance. Utilisez l'outil de calcul de KiCad pour connaître la largeur requise. Limitez l'augmentation de température (*temperature rise*) à **10 °C** et gardez l'épaisseur de cuivre à **1 oz/ft²**.

Si vous avez l'espace nécessaire, créez un plan de masse (*ground plane*). Il permet d'éviter les boucles de masse et de réduire les perturbations ainsi que les différences de tension sur la masse. Lorsque vous créez un plan, utilisez des connexions thermiques (*thermal relief*) : le PCB sera beaucoup plus facile à souder.

> **Règle absolue**
> **Ne faites jamais d'angles de 90° dans les pistes.**

Placez plusieurs vias lorsqu'un courant important est prévu afin de limiter les pertes causées par leur résistance.

<p align="center">Exemple de vias multiples</p>

N'ajoutez pas de vias sur un footprint, sauf s'il est impossible de faire autrement. C'est une mauvaise pratique.

<p align="center">Exemple de vias à éviter sur un footprint</p>

Ajoutez des points de test lorsque c'est possible pour faciliter le débogage. Les personnes qui devront régler les problèmes vous en remercieront.

## 4. Sérigraphie (*Silkscreen*)

Ajoutez des informations pertinentes sur le PCB. Le dessus doit rester professionnel; pour le dessous, vous pouvez vous permettre un peu plus de fantaisie.

### Informations à ajouter

- Numéro des petits composants ou méthode d'identification (nom du composant, utilité). Certains numéros peuvent être omis en cas de manque d'espace évident et s'il n'existe aucune autre méthode d'identification.
- Marquages importants, par exemple le sens d'un IMU.
- Symbole Biogenius, ainsi que ceux de Robotique UdeS si l'espace le permet.
- Nom des concepteurs et des validateurs. Vous faites du bon travail, soyez-en fiers!

<p align="center">Exemple de sérigraphie</p>

### Avertissements tolérés

- Sérigraphies qui se superposent.
- Footprints manquants, causés par une modification de la sérigraphie.
- Footprints qui ne correspondent plus à ceux de la bibliothèque, à la suite d'une modification de la sérigraphie.

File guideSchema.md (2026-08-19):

# Guide de réalisation des schémas

## Règles générales

Les schémas doivent respecter les conventions suivantes :

- Placer les alimentations (5 V, 48 V) vers le haut.
- Placer la masse (GND) vers le bas.
- Privilégier les labels plutôt que de longs fils traversant plusieurs zones du schéma.
- Regrouper les mounting holes avec l'alimentation et privilégier les M3.
- Séparer le schéma par blocs fonctionnels.
- Regrouper chaque fonction dans un rectangle avec un titre clair.

Exemple de séparation par blocs fonctionnels

### Pages hiérarchiques

- Créer une page distincte lorsqu'un bloc devient complexe, lorsqu'un PCB contient beaucoup de blocs ou lorsqu'il contient plusieurs exemplaires d'un composant.

Chaque PCB possède une page pour chacun des blocs suivants :

- **ALIMENTATION** : protections électriques, convertisseurs step-up et step-down.
- **CONTROLE** : contrôleur, communication, connecteurs de signaux et petits circuits nécessaires au fonctionnement du contrôleur.
- **CAPTEUR** : autres circuits de la carte.

Chaque PCB a une page:

Exemple de pages hiérarchiques

### Notes de conception

Ajouter des notes lorsque la conception n'est pas évidente.

Exemple de note de conception

## Datasheets

Une datasheet doit être associée à tous les circuits intégrés (chips) pour faciliter les révisions.

Exemple de champ Datasheet

Le champ Datasheet doit pointer vers la page officielle du fabricant.

**Exemples :**

- ESP32-C3 Datasheet (Espressif)
- LSM6DSV320X Datasheet (STMicroelectronics)
- TCAN332 Datasheet (Texas Instruments)

Aucune puce ne doit être utilisée sans avoir consulté sa datasheet.

## Notation des composants

### Convention de nommage des composants
| Type | Préfixe | Exemple |
| :--- | :--- | :--- |
| Résistance | R | R101 |
| Condensateur | C | C101 |
| Inductance | L | L101 |
| Ferrite | FB | FB101 |
| Diode | D | D101 |
| LED | D | D101 |
| Transistor BJT | Q | Q101 |
| MOSFET | Q | Q102 |
| Circuit intégré | U | U101 |
| Régulateur | U | U102 |
| Convertisseur DC/DC | U | U103 |
| Quartz | Y | Y101 |
| Oscillateur | Y | Y102 |
| Fusible | F | F101 |
| Interrupteur | SW | SW101 |
| Bouton poussoir | SW | SW102 |
| Connecteur | J | J101 |
| Relais | K | K101 |
| Jumper | JP | JP101 |
| Test Point | TP | TP101 |
| Transformateur | T | T101 |
| Antenne | ANT | ANT1 |
### Convention de numérotation

Plage de numéros réservés à chaque sous-système.

| Bloc | Plage |
| :--- | :--- |
| Alimentations/protections | 100–199 |
| Microcontrôleurs/Communication | 200–299 |
| Capteurs | 300–399 |

### Gestion des composants pour le BOM

Tous les composants doivent posséder les champs suivants :
| Nom | Quoi | Exemple |
| :--- | :--- | :--- |
| **Reference** | Numéro d'identification du composant | U3, R101 |
| **Value** | Valeur du composant | ESP32-S3-WROOM-1-N16R2, 10pF |
| **Footprint** | Format des pads pour les composants | Resistor_SMD:R_0603_1608Metric_Pad0.98x0.95mm_HandSolder |
| **Datasheet** | Documentation de la puce | Requis seulement pour les puces |
| **Description** | Information particulière | Résistance shunt pour la lecture du courant |
| **Digi-Key_PN** | Numéro Digi-Key des composants pour les BOM automatiques (doit être à jour) | 5407-ESP32-S3-WROOM-1-N16R2CT-ND |
Exemple de propriétés des composants

Le BOM exporté doit permettre l'importation directe dans :

### DigiKey BOM Manager

Afin de générer automatiquement le panier, il faut que toutes les composantes aient leur **Digi-Key_PN**.

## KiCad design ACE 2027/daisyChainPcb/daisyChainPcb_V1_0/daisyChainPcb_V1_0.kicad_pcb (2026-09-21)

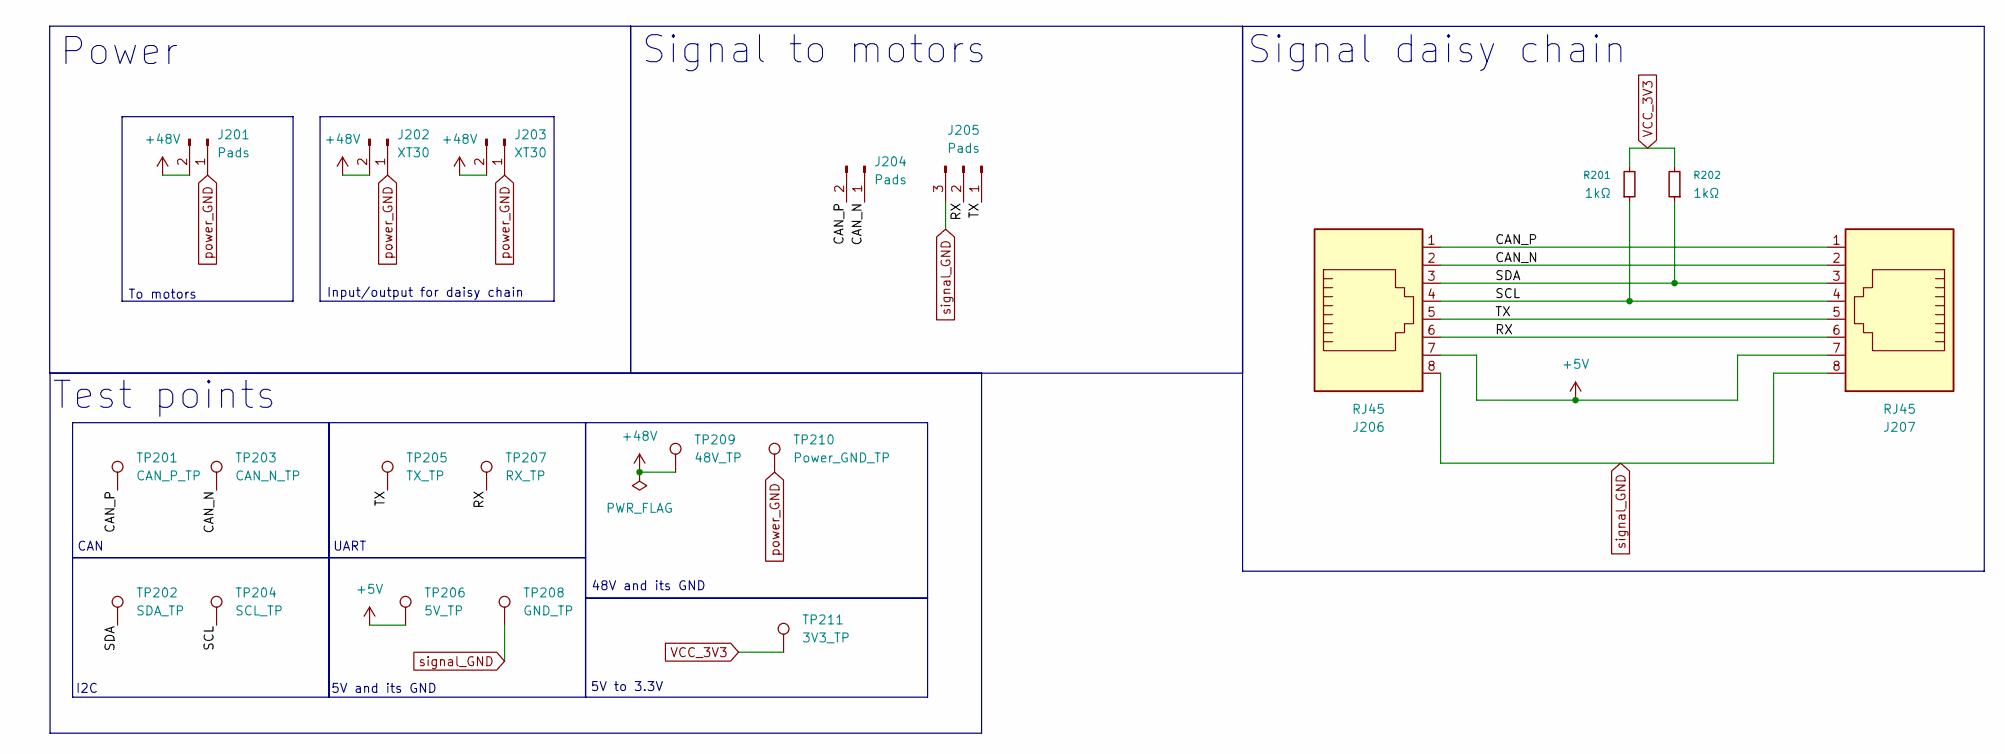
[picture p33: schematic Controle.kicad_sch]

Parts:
J201: Pads; motorPads
J202, J203: XT30; AMASS_XT30PW-M_1x02_P2.50mm_Horizontal
J204: Pads; CAN_pads
J205: Pads; UART_pads
J206, J207: RJ45; RJ45_Amphenol_54602-x08_Horizontal; Digi-Key_PN 609-1046-ND
R201, R202: 1kΩ; R_0805_2012Metric_Pad1.20x1.40mm_HandSolder; Digi-Key_PN 541-1.00KCCT-ND
TP201: CAN_P_TP; TestPoint_Pad_D2.0mm
TP202: SDA_TP; TestPoint_Pad_D2.0mm
TP203: CAN_N_TP; TestPoint_Pad_D2.0mm
TP204: SCL_TP; TestPoint_Pad_D2.0mm
TP205: TX_TP; TestPoint_Pad_D2.0mm
TP206: 5V_TP; TestPoint_Pad_D2.0mm
TP207: RX_TP; TestPoint_Pad_D2.0mm
TP208: GND_TP; TestPoint_Pad_D2.0mm
TP209: 48V_TP; TestPoint_Pad_D2.0mm
TP210: Power_GND_TP; TestPoint_Pad_D2.0mm
TP211: 3V3_TP; TestPoint_Pad_D2.0mm

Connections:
+5V: J206.7, J207.7, TP206.1 (1_1); also elsewhere on the board
+48V: J201.2, J202.2, J203.2, TP209.1 (1_1)
/Controle/CAN_N: J204.1, J206.2, J207.2, TP203.1 (1_1)
/Controle/CAN_P: J204.2, J206.1, J207.1, TP201.1 (1_1)
/Controle/RX: J205.2, J206.6, J207.6, TP207.1 (1_1)
/Controle/SCL: J206.4, J207.4, R201.1, TP204.1 (1_1)
/Controle/SDA: J206.3, J207.3, R202.1, TP202.1 (1_1)
/Controle/TX: J205.1, J206.5, J207.5, TP205.1 (1_1)
VCC_3V3: R201.2, R202.2, TP211.1 (1_1); also elsewhere on the board
power_GND: J201.1, J202.1, J203.1, TP210.1 (1_1)
signal_GND: J205.3, J206.8, J207.8, TP208.1 (1_1); also elsewhere on the board

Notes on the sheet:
48V and its GND
To motors
Power
I2C
Test points
5V and its GND
Input/output for daisy chain
Signal daisy chain
Signal to motors
UART
5V to 3.3V
CAN

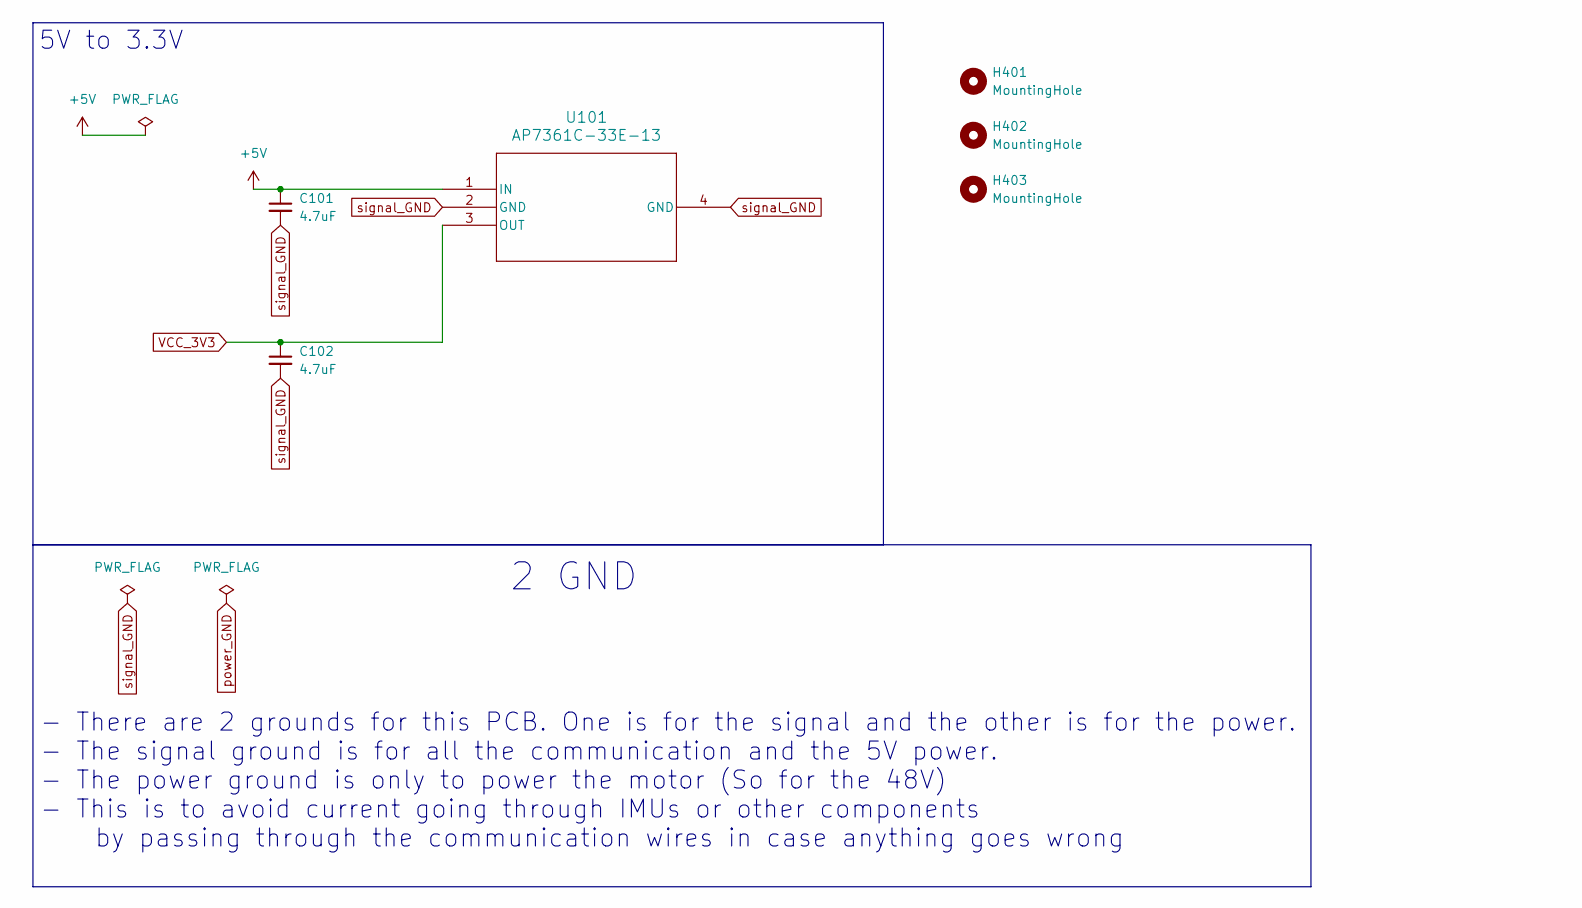
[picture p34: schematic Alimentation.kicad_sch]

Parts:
C101, C102: 4.7uF; C_0805_2012Metric_Pad1.18x1.45mm_HandSolder; Digi-Key_PN 490-12394-1-ND
H401, H402, H403: MountingHole; MountingHole_4.3mm_M4
U101: AP7361C-33E-13; SOT223_DIO-L

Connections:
+5V: C101.1, U101.1 (IN); also elsewhere on the board
VCC_3V3: C102.1, U101.3 (OUT); also elsewhere on the board
signal_GND: C101.2, C102.2, U101.2 (GND), U101.4 (GND); also elsewhere on the board

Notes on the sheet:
- There are 2 grounds for this PCB. One is for the signal and the other is for the power. - The signal ground is for all the communication and the 5V power. - The power ground is only to power the motor (So for the 48V) - This is to avoid current going through IMUs or other components by passing th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
5V to 3.3V
2 GND

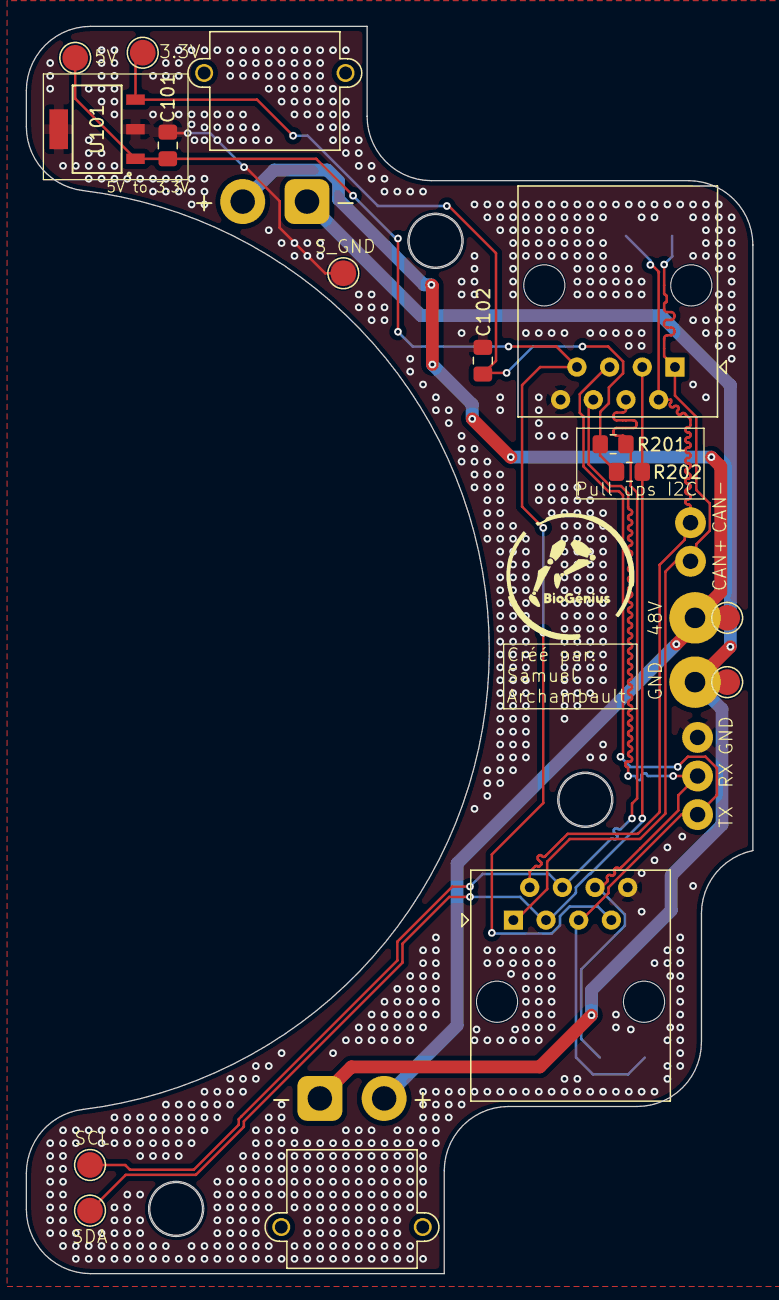
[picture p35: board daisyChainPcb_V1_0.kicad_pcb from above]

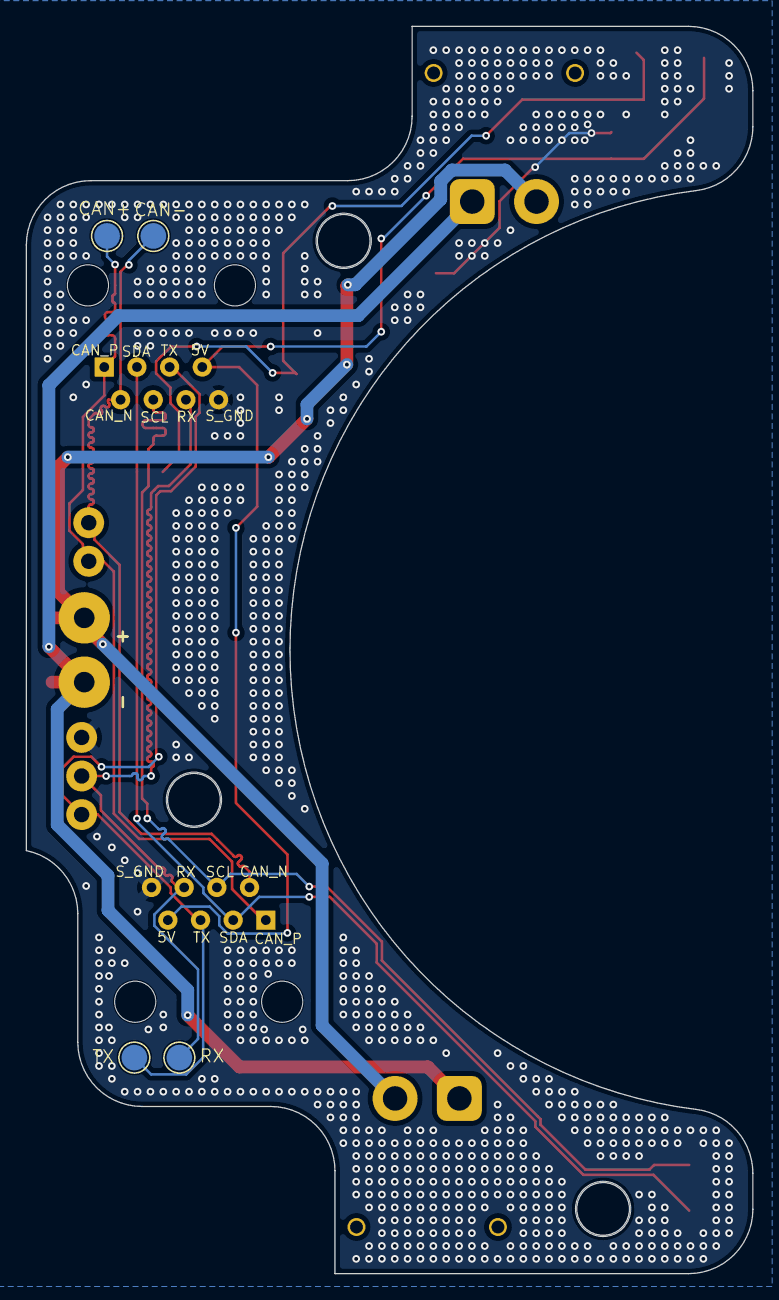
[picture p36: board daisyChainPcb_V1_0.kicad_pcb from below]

Board: 2 copper layers, 56.5 x 97.0 mm, 26 parts (4 on the bottom side), 11 nets.

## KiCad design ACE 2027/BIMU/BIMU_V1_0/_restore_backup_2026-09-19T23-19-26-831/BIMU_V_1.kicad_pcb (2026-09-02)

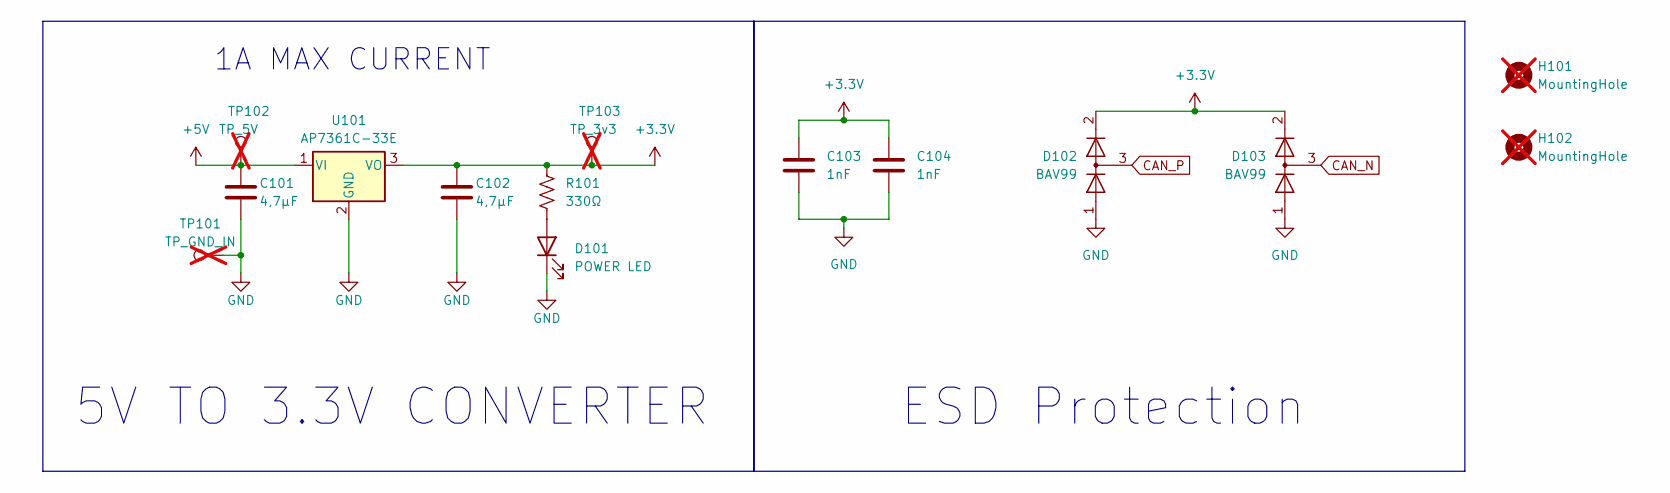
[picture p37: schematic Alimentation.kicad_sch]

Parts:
C101, C102: 4,7µF; C_0805_2012Metric_Pad1.18x1.45mm_HandSolder; Digi-Key_PN 1276-2970-1-ND
C103, C104: 1nF; C_1812_4532Metric_Pad1.57x3.40mm_HandSolder; Digi-Key_PN 399-C1812C104MDRACTUCT-ND
D101: POWER LED; LED_0805_2012Metric_Pad1.15x1.40mm_HandSolder; Digi-Key_PN 1516-QBLP631-IG5CT-ND
D102, D103: BAV99; SOT-23; Digi-Key_PN 1655-BAV99CT-ND
H101, H102: MountingHole; MountingHole_3.2mm_M3_ISO14580; not fitted
R101: 330Ω; R_0805_2012Metric_Pad1.20x1.40mm_HandSolder; Digi-Key_PN 541-4168-1-ND
TP101: TP_GND_IN; TestPoint_Pad_1.0x1.0mm; not fitted
TP102: TP_5V; TestPoint_Pad_1.0x1.0mm; not fitted
TP103: TP_3v3; TestPoint_Pad_1.0x1.0mm; not fitted
U101: AP7361C-33E; SOT-223-3_TabPin2; Digi-Key_PN AP7361C-33E-13DICT-ND

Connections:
+3.3V: C102.2, C103.1, C104.1, D102.2 (A), D103.2 (A), R101.1, TP103.1 (1_1), U101.3 (VO); also elsewhere on the board
+5V: C101.2, TP102.1 (1_1), U101.1 (VI); also elsewhere on the board
CAN_N: D103.3 (K); also elsewhere on the board
CAN_P: D102.3 (K); also elsewhere on the board
GND: C101.1, C102.1, C103.2, C104.2, D101.1 (K), D102.1 (K), D103.1 (K), TP101.1 (1_1), U101.2 (GND); also elsewhere on the board
unnamed: D101.2 (A), R101.2

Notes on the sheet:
ESD Protection
1A MAX CURRENT
5V TO 3.3V CONVERTER

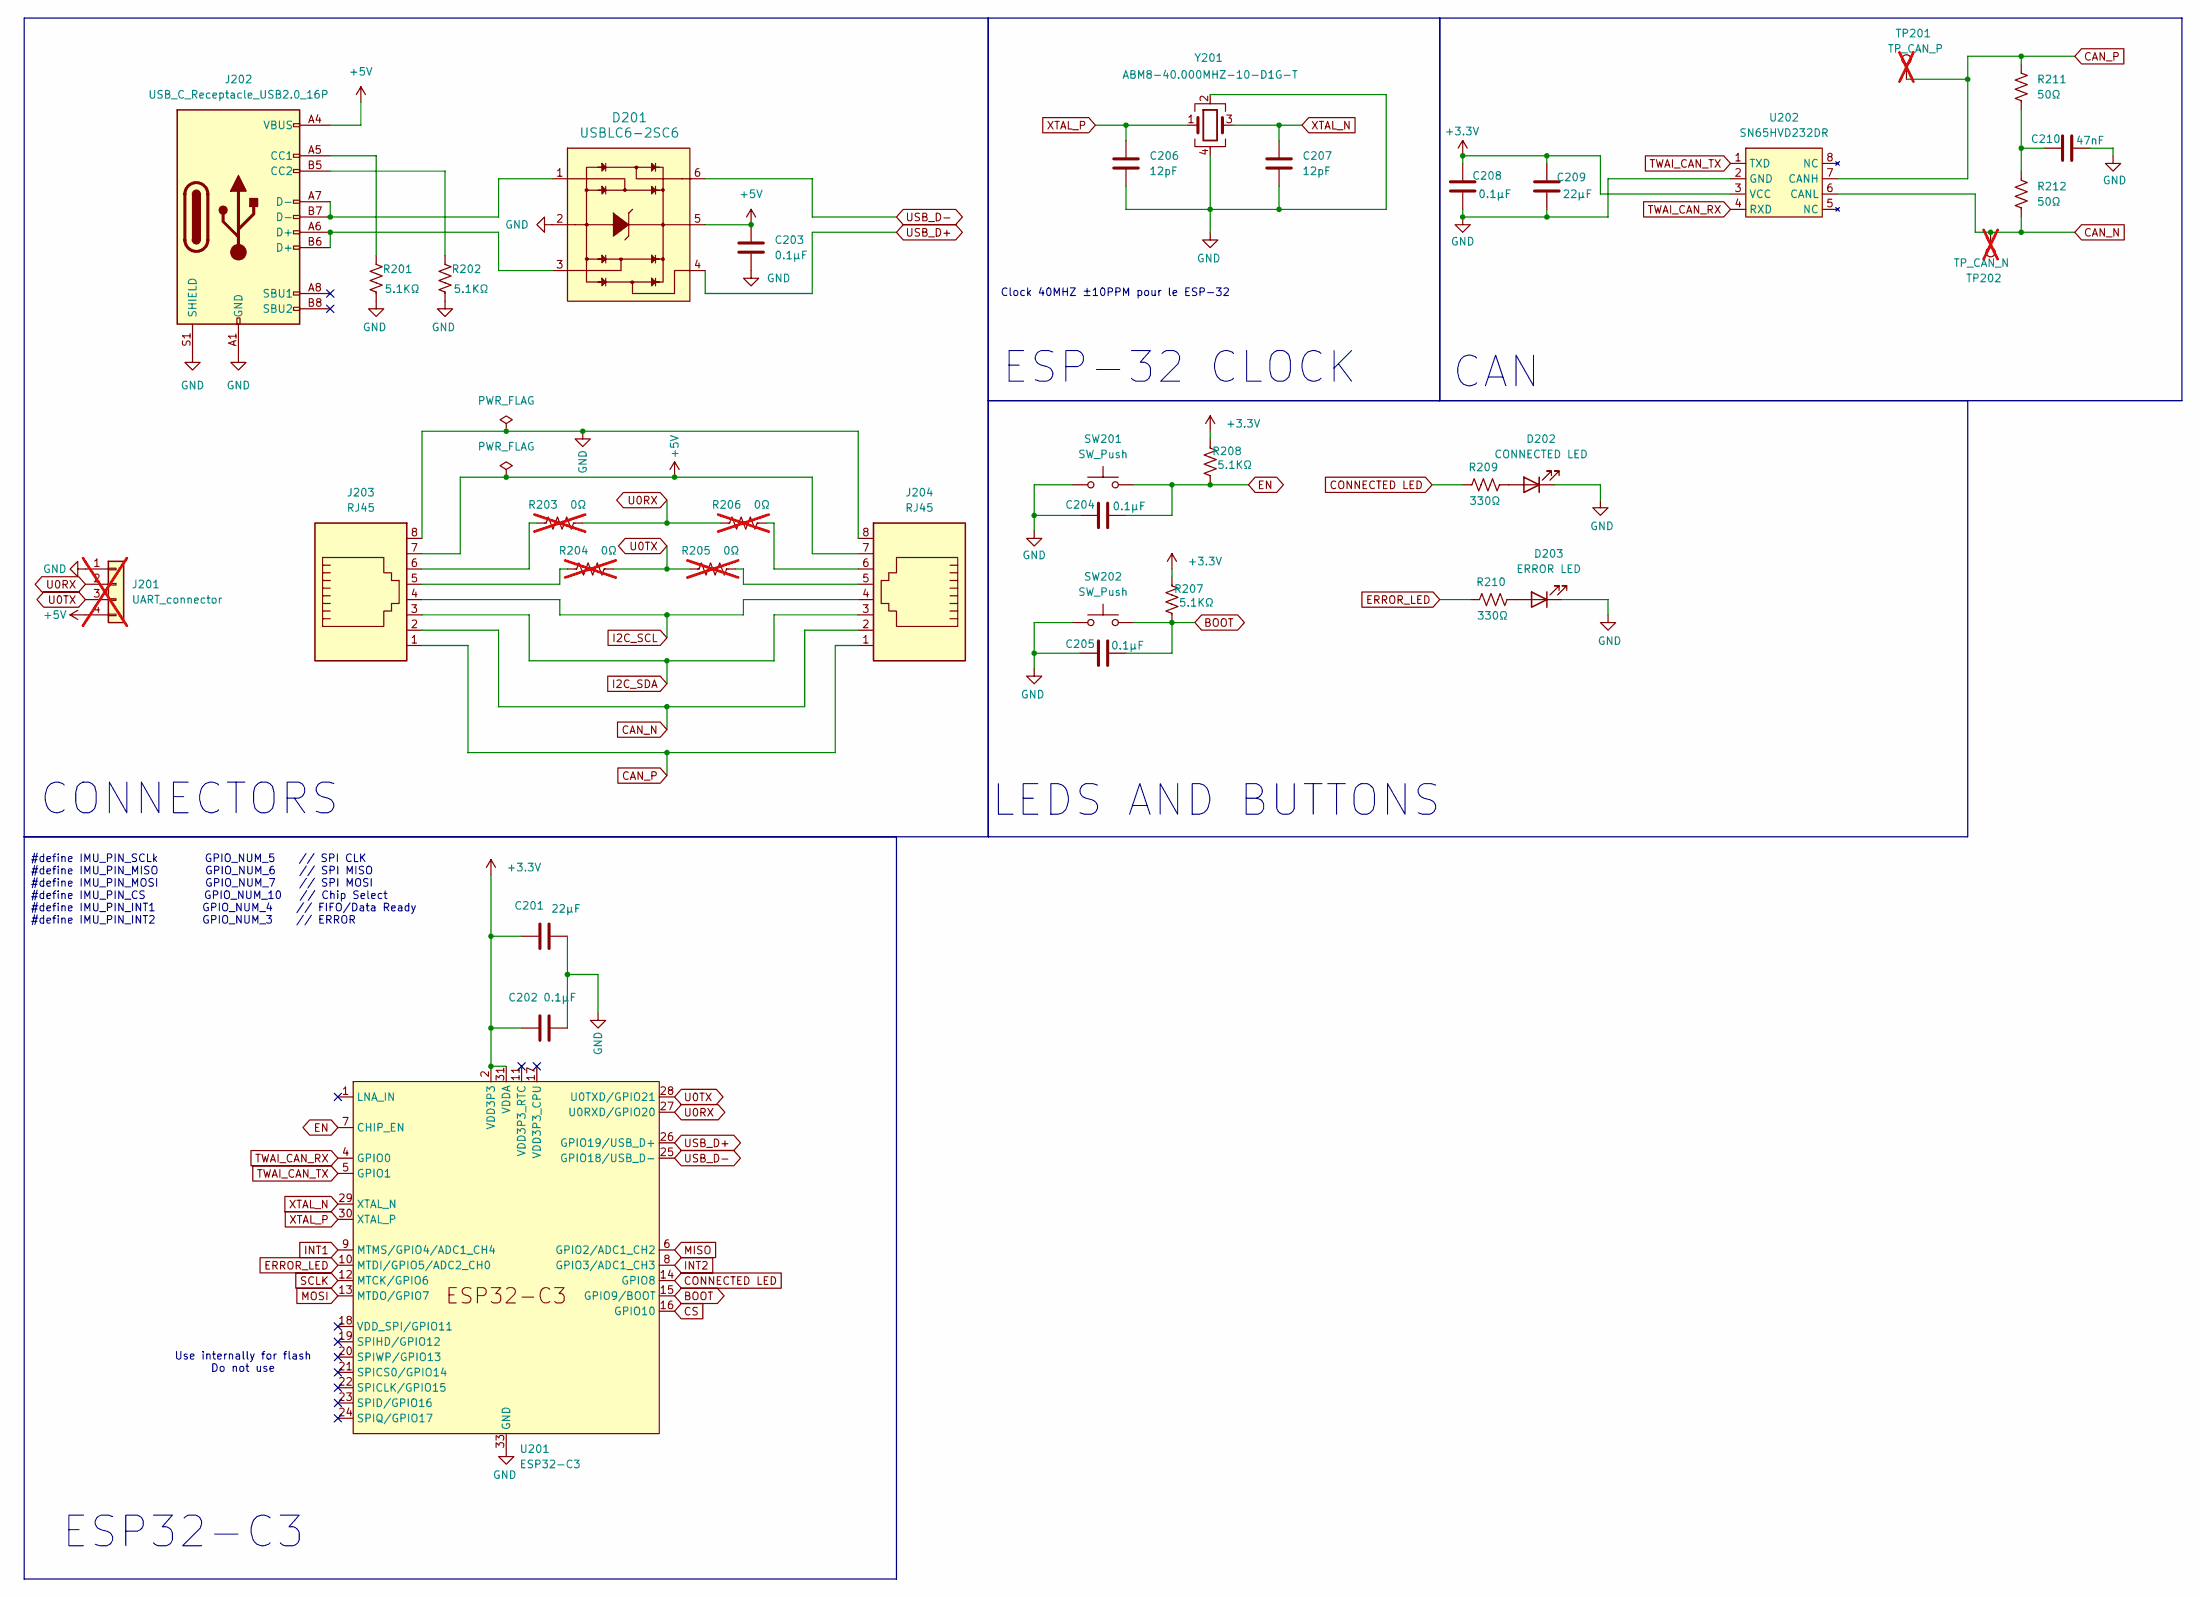
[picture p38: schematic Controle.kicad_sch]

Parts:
C201, C209: 22μF; C_0805_2012Metric_Pad1.18x1.45mm_HandSolder; Digi-Key_PN 1276-6501-1-ND
C202, C203, C204, C205, C208: 0.1μF; C_0805_2012Metric_Pad1.18x1.45mm_HandSolder; Digi-Key_PN 399-C0805C104K5RACTUCT-ND
C206, C207: 12pF; C_0805_2012Metric_Pad1.18x1.45mm_HandSolder; Digi-Key_PN 399-C0805C120J8HACTUCT-ND
C210: 47nF; C_0603_1608Metric_Pad1.08x0.95mm_HandSolder; Digi-Key_PN 1276-2960-1-ND
D201: USBLC6-2SC6; SOT23-6L; MPN USBLC6-2SC6; Digi-Key_PN 4518-USBLC6-2SC6CT-ND
D202: CONNECTED LED; LED_0805_2012Metric_Pad1.15x1.40mm_HandSolder; Digi-Key_PN 1516-QBLP631-IB5CT-ND
D203: ERROR LED; LED_0805_2012Metric_Pad1.15x1.40mm_HandSolder; Digi-Key_PN 1516-QBLP631-R5-2897CT-ND
J201: UART_connector; PinSocket_1x04_P2.54mm_Vertical; not fitted
J202: USB_C_Receptacle_USB2.0_16P; USB_C_Receptacle_GCT_USB4105-xx-A_16P_TopMnt_Horizontal; Digi-Key_PN 2073-USB4105-GF-ACT-ND
J203, J204: RJ45; RJ45_Amphenol_54602-x08_Horizontal; Digi-Key_PN 609-1046-ND
R201, R202, R207, R208: 5.1KΩ; R_0805_2012Metric_Pad1.20x1.40mm_HandSolder; Digi-Key_PN 541-CRCW08055K10FKEACCT-ND
R203, R204, R205, R206: 0Ω; R_0402_1005Metric_Pad0.72x0.64mm_HandSolder; not fitted
R209, R210: 330Ω; R_0805_2012Metric_Pad1.20x1.40mm_HandSolder; Digi-Key_PN 541-4168-1-ND
R211, R212: 50Ω; R_0805_2012Metric_Pad1.20x1.40mm_HandSolder; Digi-Key_PN 541-CRCW080550R0FKTACT-ND
SW201, SW202: SW_Push; SW_SPST_B3U-1000P; Digi-Key_PN SW1021CT-ND
TP201: TP_CAN_P; TestPoint_Pad_1.0x1.0mm; not fitted
TP202: TP_CAN_N; TestPoint_Pad_1.0x1.0mm; not fitted
U201: ESP32-C3; QFN-32-1EP_5x5mm_P0.5mm_EP3.45x3.45mm; Digi-Key_PN 1904-ESP32-C3FH4CT-ND
U202: SN65HVD232DR; SOIC-8_3.9x4.9mm_P1.27mm; Digi-Key_PN 296-26344-1-ND
Y201: ABM8-40.000MHZ-10-D1G-T; Crystal_SMD_2016-4Pin_2.0x1.6mm; Digi-Key_PN 535-14997-1-ND

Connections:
+3.3V: C201.1, C202.1, C208.1, C209.1, R207.2, R208.2, U201.2 (VDD3P3), U201.3 (VDD3P3), U201.31 (VDDA), U201.32 (VDDA), U202.3 (VCC); also elsewhere on the board
+5V: C203.1, D201.5, J201.4, J202.A4 (VBUS), J202.A9 (VBUS), J202.B4 (VBUS), J202.B9 (VBUS), J203.7, J204.7; also elsewhere on the board
BOOT: C205.1, R207.1, SW202.2, U201.15 (GPIO9/BOOT)
CAN_N: J203.2, J204.2, R212.2, TP202.1 (1_1), U202.6 (CANL); also elsewhere on the board
CAN_P: J203.1, J204.1, R211.1, TP201.1 (1_1), U202.7 (CANH); also elsewhere on the board
CONNECTED LED: R209.2, U201.14 (GPIO8)
CS: U201.16 (GPIO10); also elsewhere on the board
EN: C204.1, R208.1, SW201.2, U201.7 (CHIP_EN)
ERROR_LED: R210.2, U201.10 (MTDI/GPIO5/ADC2_CH0)
GND: C201.2, C202.2, C203.2, C204.2, C205.2, C206.2, C207.2, C208.2, C209.2, C210.1, D201.2, D202.1 (K), D203.1 (K), J201.1, J202.A1 (GND), J202.A12 (GND), J202.B1 (GND), J202.B12 (GND), J202.S1 (SHIELD), J203.8, J204.8, R201.2, R202.2, SW201.1, SW202.1, U201.33 (GND), U202.2 (GND), Y201.2, Y201.4; also elsewhere on the board
I2C_SCL: J203.4, J204.4
I2C_SDA: J203.3, J204.3
INT1: U201.9 (MTMS/GPIO4/ADC1_CH4); also elsewhere on the board
INT2: U201.8 (GPIO3/ADC1_CH3); also elsewhere on the board
MISO: U201.6 (GPIO2/ADC1_CH2); also elsewhere on the board
MOSI: U201.13 (MTDO/GPIO7); also elsewhere on the board
unnamed: C210.2, R211.2, R212.1
unnamed: D201.1, J202.A7 (D-), J202.B7 (D-)
unnamed: D201.3, J202.A6 (D+), J202.B6 (D+)
unnamed: D202.2 (A), R209.1
unnamed: D203.2 (A), R210.1
unnamed: J202.A5 (CC1), R201.1
unnamed: J202.B5 (CC2), R202.1
unnamed: J203.5, R204.1
unnamed: J203.6, R203.1
unnamed: J204.5, R205.2
unnamed: J204.6, R206.2
SCLK: U201.12 (MTCK/GPIO6); also elsewhere on the board
TWAI_CAN_RX: U201.4 (GPIO0), U202.4 (RXD)
TWAI_CAN_TX: U201.5 (GPIO1), U202.1 (TXD)
U0RX: J201.2, R203.2, R206.1, U201.27 (U0RXD/GPIO20)
U0TX: J201.3, R204.2, R205.1, U201.28 (U0TXD/GPIO21)
USB_D+: D201.4, U201.26 (GPIO19/USB_D+)
USB_D-: D201.6, U201.25 (GPIO18/USB_D-)
XTAL_N: C207.1, U201.29 (XTAL_N), Y201.3
XTAL_P: C206.1, U201.30 (XTAL_P), Y201.1

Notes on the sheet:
ESP32-C3
#define IMU_PIN_SCLk GPIO_NUM_5 // SPI CLK #define IMU_PIN_MISO GPIO_NUM_6 // SPI MISO #define IMU_PIN_MOSI GPIO_NUM_7 // SPI MOSI #define IMU_PIN_CS GPIO_NUM_10 // Chip Select #define IMU_PIN_INT1 GPIO_NUM_4 // FIFO/Data Ready #define IMU_PIN_INT2 GPIO_NUM_3 // ERROR
CONNECTORS
Use internally for flash Do not use
ESP-32 CLOCK
LEDS AND BUTTONS
CAN
Clock 40MHZ ±10PPM pour le ESP-32

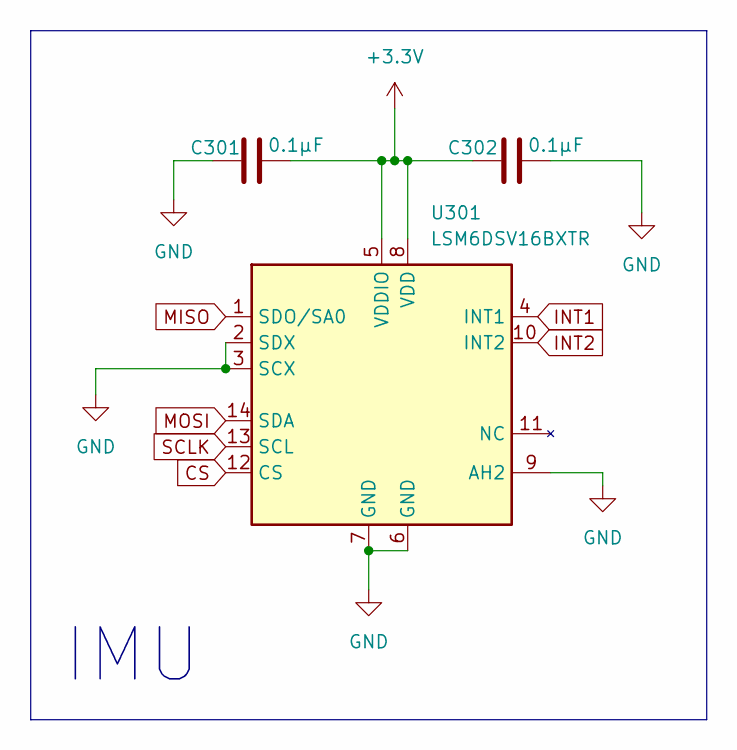
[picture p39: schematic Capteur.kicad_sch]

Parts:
C301, C302: 0.1μF; C_0805_2012Metric_Pad1.18x1.45mm_HandSolder; Digi-Key_PN 399-C0805C104K5RACTUCT-ND
U301: LSM6DSV16BXTR; LGA-14_3x2.5mm_P0.5mm_LayoutBorder3x4y; Digi-Key_PN 497-LSM6DSV16BXTRCT-ND

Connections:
+3.3V: C301.1, C302.2, U301.5 (VDDIO), U301.8 (VDD); also elsewhere on the board
CS: U301.12 (CS); also elsewhere on the board
GND: C301.2, C302.1, U301.2 (SDX), U301.3 (SCX), U301.6 (GND), U301.7 (GND), U301.9 (AH2); also elsewhere on the board
INT1: U301.4 (INT1); also elsewhere on the board
INT2: U301.10 (INT2); also elsewhere on the board
MISO: U301.1 (SDO/SA0); also elsewhere on the board
MOSI: U301.14 (SDA); also elsewhere on the board
SCLK: U301.13 (SCL); also elsewhere on the board

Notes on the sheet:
IMU

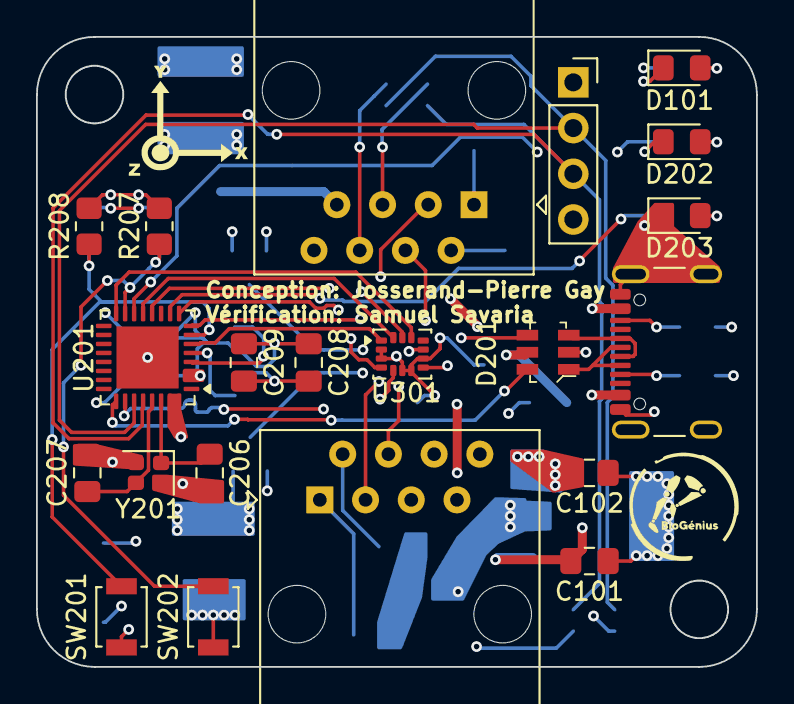
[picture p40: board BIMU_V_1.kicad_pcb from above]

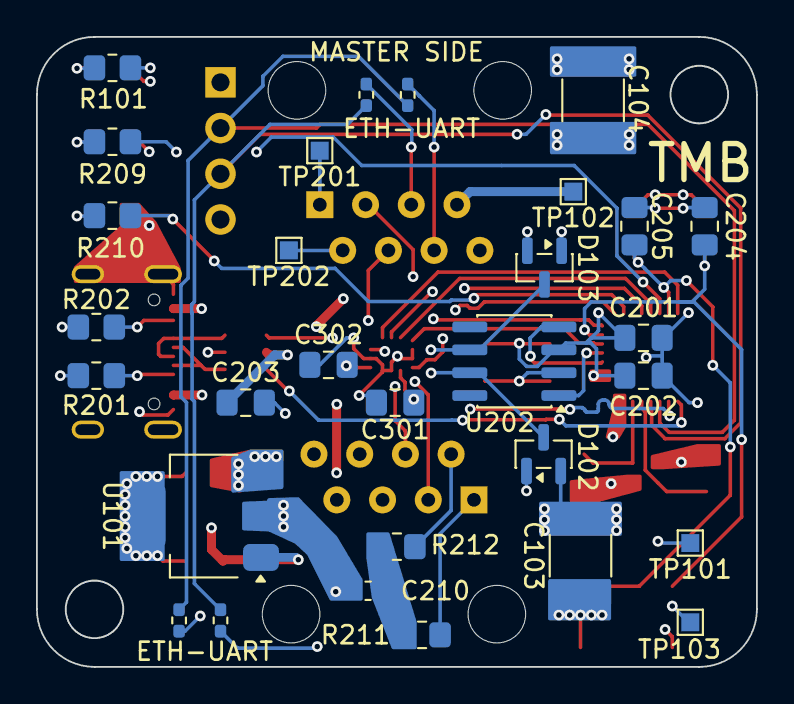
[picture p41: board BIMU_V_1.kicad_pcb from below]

Board: 4 copper layers, 40.0 x 35.0 mm, 53 parts (30 on the bottom side), 37 nets.

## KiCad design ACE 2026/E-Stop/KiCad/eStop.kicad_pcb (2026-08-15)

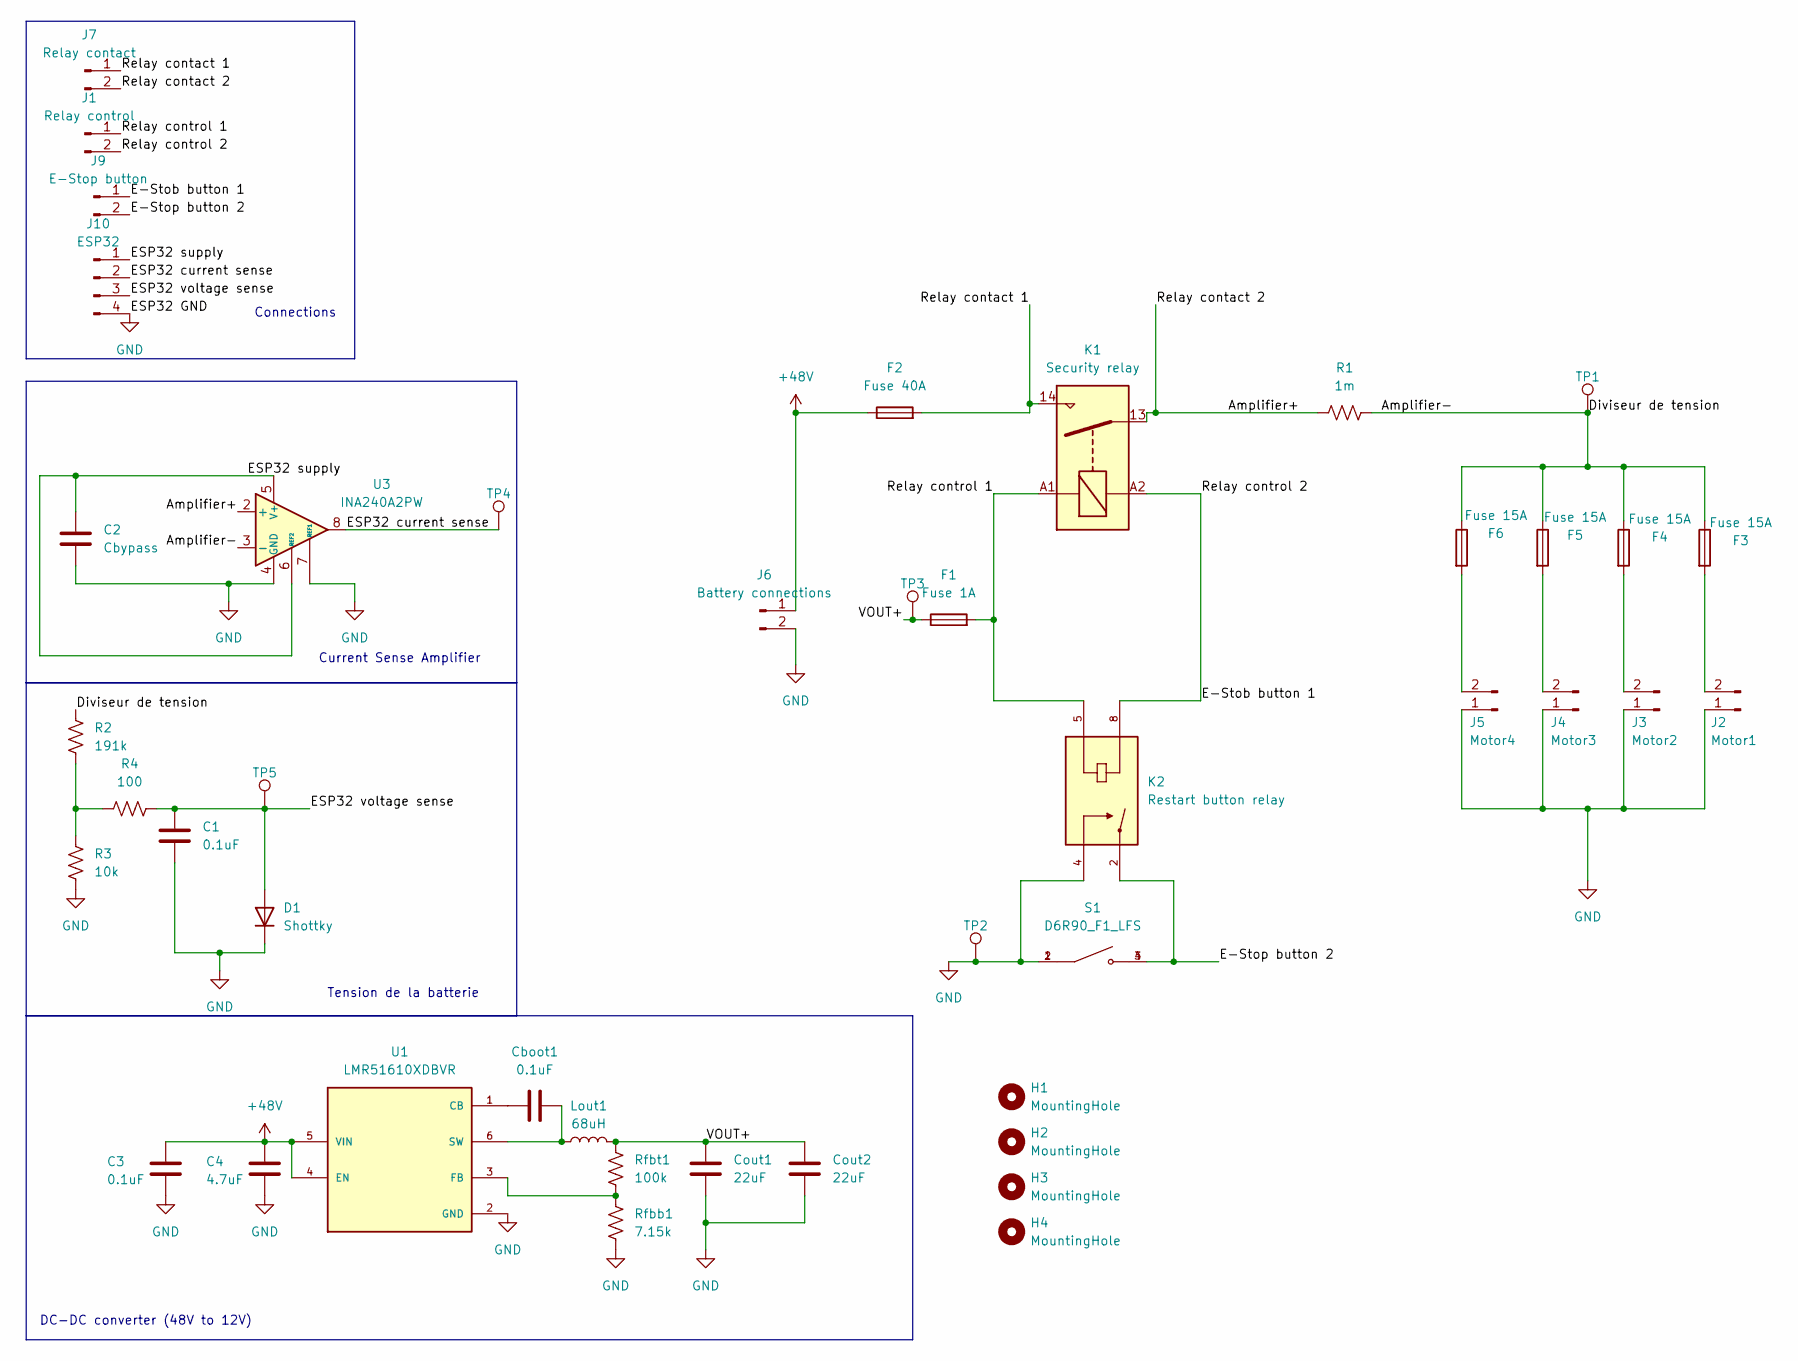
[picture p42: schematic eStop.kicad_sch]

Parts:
C1: 0.1uF; C_0805_2012Metric
C2: Cbypass; C_0805_2012Metric
C3: 0.1uF; C_1210_3225Metric_Pad1.33x2.70mm_HandSolder
C4: 4.7uF; C_2220_5750Metric_Pad1.97x5.40mm_HandSolder
Cboot1: 0.1uF; C_0805_2012Metric
Cout1, Cout2: 22uF; C_1210_3225Metric_Pad1.33x2.70mm_HandSolder
D1: Shottky; D_0603_1608Metric_Pad1.05x0.95mm_HandSolder
F1: Fuse 1A; 3557-15_KEY
F2: Fuse 40A; 40A fuse holder
F3, F4, F5, F6: Fuse 15A; 40A fuse holder
H1, H2, H3, H4: MountingHole; MountingHole_3.2mm_M3_DIN965
J1: Relay control; JST_EH_B2B-EH-A_1x02_P2.50mm_Vertical
J2: Motor1; AMASS_XT30U-F_1x02_P5.0mm_Vertical
J3: Motor2; AMASS_XT30U-F_1x02_P5.0mm_Vertical
J4: Motor3; AMASS_XT30U-F_1x02_P5.0mm_Vertical
J5: Motor4; AMASS_XT30U-F_1x02_P5.0mm_Vertical
J6: Battery connections; AMASS_XT60-M_1x02_P7.20mm_Vertical
J7: Relay contact; AMASS_XT60-M_1x02_P7.20mm_Vertical
J9: E-Stop button; JST_EH_B2B-EH-A_1x02_P2.50mm_Vertical
J10: ESP32; JST_EH_B4B-EH-A_1x04_P2.50mm_Vertical
K1: Security relay
K2: Restart button relay; RELAY_G6L-1P_DC12; Digi-Key_PN Z1229-ND
Lout1: 68uH; L_Bourns_SRR1260
R1: 1m; R_2512_6332Metric_Pad1.40x3.35mm_HandSolder
R2: 191k; R_0805_2012Metric
R3: 10k; R_0805_2012Metric
R4: 100; R_0805_2012Metric
Rfbb1: 7.15k; R_0805_2012Metric
Rfbt1: 100k; R_0805_2012Metric
S1: D6R90_F1_LFS; SW_D6R90_F1_LFS; PARTREV N/A
TP1, TP2, TP3, TP4, TP5: 1.0mm; TestPoint_Pad_D4.0mm
U1: LMR51610XDBVR; SOT95P280X145-6N; PARTREV B; DigiKey_Part_Number 296-LMR51610XDBVRCT-ND
U3: INA240A2PW; TSSOP-8_4.4x3mm_P0.65mm

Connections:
+48V: C3.1, C4.1, F2.1, J6.1, U1.4 (EN), U1.5 (VIN)
/Amplifier+: J7.2, K1.13, R1.1, U3.2 (+)
/Amplifier-: F3.1, F4.1, F5.1, F6.1, R1.2, R2.2, TP1.1, U3.3 (-)
/E-Stob button 1: J1.2, J9.1, K1.A2, K2.8; also elsewhere on the board
/E-Stop button 2: J9.2, K2.2, S1.3, S1.4; also elsewhere on the board
/ESP32 current sense: J10.2, TP4.1, U3.8; also elsewhere on the board
/ESP32 supply: C2.1, J10.1, U3.5 (V+), U3.6 (REF2); also elsewhere on the board
/ESP32 voltage sense: C1.1, D1.2 (A), J10.3, R4.1, TP5.1; also elsewhere on the board
/Relay contact 1: F2.2, J7.1, K1.14
/Relay control 1: F1.3, J1.1, K1.A1, K2.5; also elsewhere on the board
/VOUT+: Cout1.2, Cout2.2, F1.1, Lout1.2, Rfbt1.2, TP3.1
GND: C1.2, C2.2, C3.2, C4.2, Cout1.1, Cout2.1, D1.1 (K), J2.1, J3.1, J4.1, J5.1, J6.2, J10.4, K2.4, R3.1, Rfbb1.1, S1.1, S1.2, TP2.1, U1.2 (GND), U3.1 (GND), U3.4 (GND), U3.7 (REF1); also elsewhere on the board
unnamed: F3.2, J2.2
unnamed: F4.2, J3.2
unnamed: F5.2, J4.2
unnamed: F6.2, J5.2
unnamed: R2.1, R3.2, R4.2
unnamed: Cboot1.1, U1.1 (CB)
unnamed: Rfbb1.2, Rfbt1.1, U1.3 (FB)
unnamed: Cboot1.2, Lout1.1, U1.6 (SW)

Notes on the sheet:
Current Sense Amplifier
DC-DC converter (48V to 12V)
Tension de la batterie
Connections

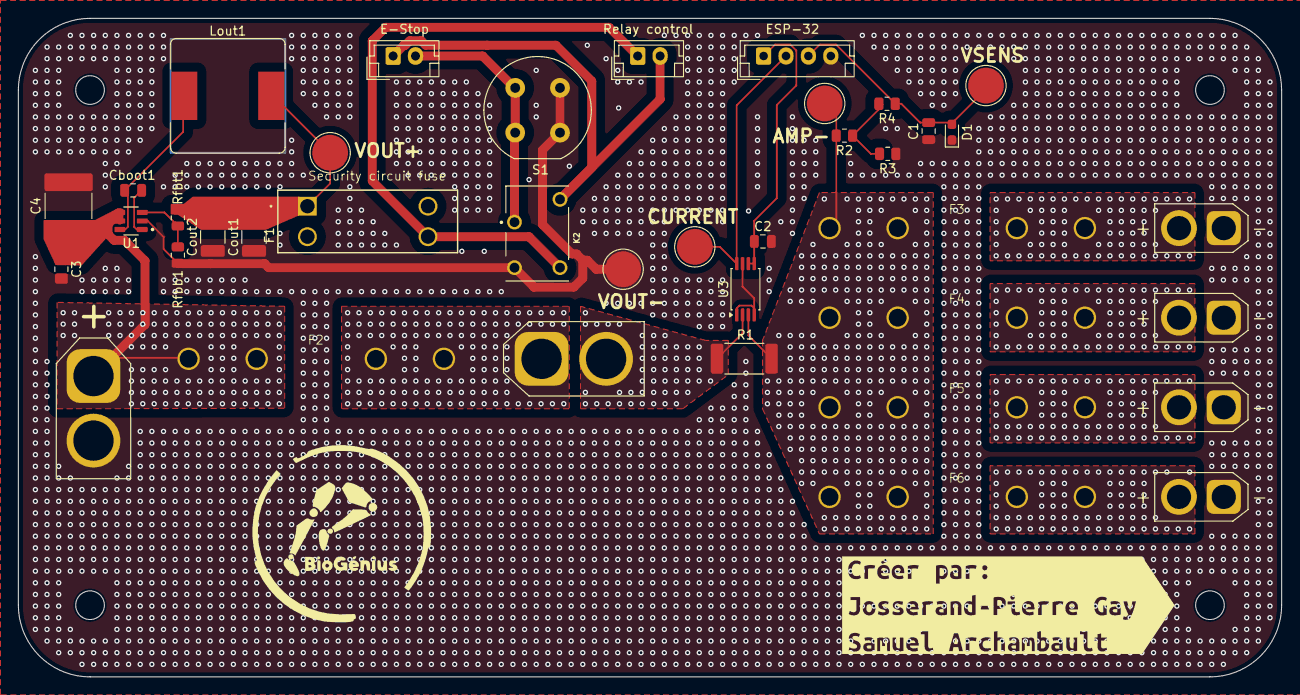
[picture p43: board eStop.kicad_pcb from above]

Board: 2 copper layers, 141.0 x 73.5 mm, 44 parts (0 on the bottom side), 20 nets.

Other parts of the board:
E-Stop: E-Stop button; JST_EH_B2B-EH-A_1x02_P2.50mm_Vertical
ESP-32 : ESP32; JST_EH_B4B-EH-A_1x04_P2.50mm_Vertical
Relay control: Relay control; JST_EH_B2B-EH-A_1x02_P2.50mm_Vertical
kibuzzard-69BC9173: G***; kibuzzard-69BC9173

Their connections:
/E-Stob button 1: E-Stop.1, Relay control.2; also elsewhere on the board
/E-Stop button 2: E-Stop.2; also elsewhere on the board
/ESP32 current sense: ESP-32.2; also elsewhere on the board
/ESP32 supply: ESP-32.1; also elsewhere on the board
/ESP32 voltage sense: ESP-32.3; also elsewhere on the board
/Relay control 1: Relay control.1; also elsewhere on the board
GND: ESP-32.4; also elsewhere on the board

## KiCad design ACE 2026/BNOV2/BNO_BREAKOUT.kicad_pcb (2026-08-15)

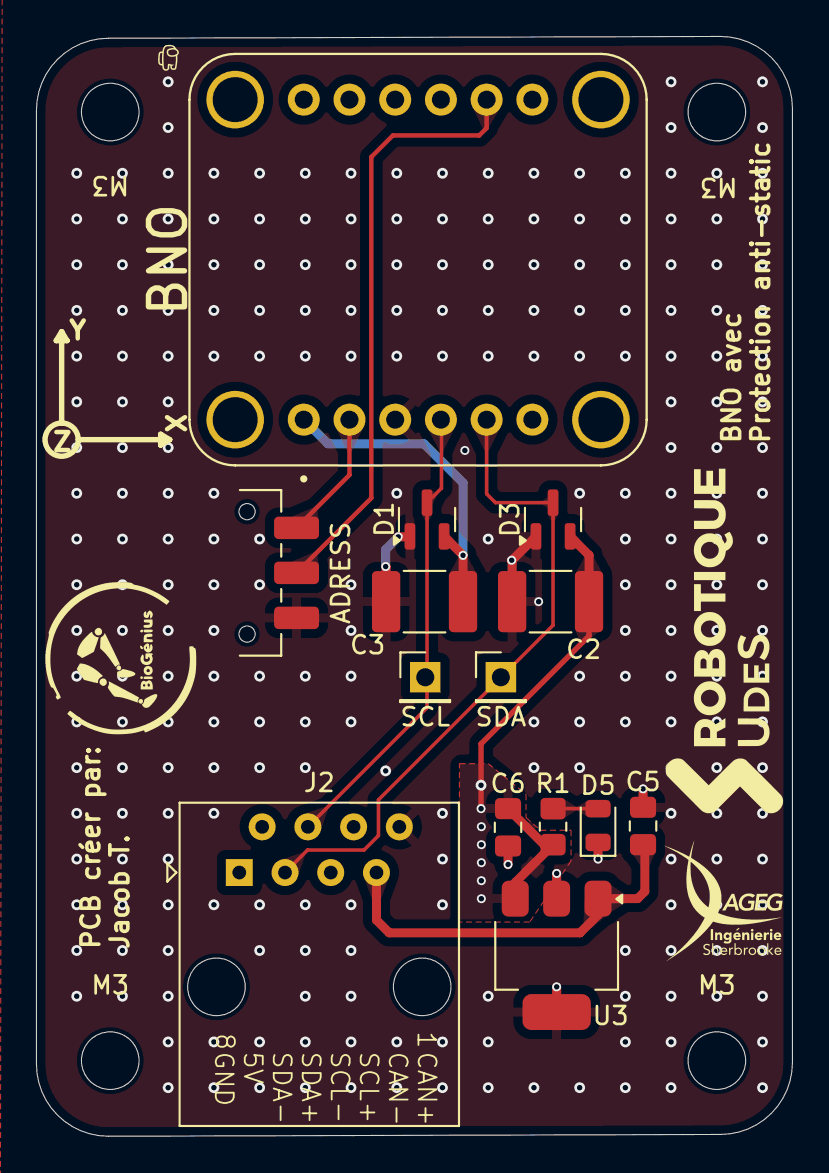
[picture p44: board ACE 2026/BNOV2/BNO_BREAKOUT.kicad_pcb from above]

Board: 2 copper layers, 42.0 x 61.1 mm, 16 parts (0 on the bottom side), 8 nets.

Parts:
ADRESS: SW_SPDT; SW_SPDT_CK_JS102011SAQN
BNO: 4754; MODULE_4754
C2, C3: 1n; C_1812_4532Metric_Pad1.57x3.40mm_HandSolder
C5, C6: 4,7µF; C_0805_2012Metric_Pad1.18x1.45mm_HandSolder
D1, D3: BAV99; SOT-23
D5: Green_power; D_0805_2012Metric
J2: RJ45; RJ45_Amphenol_54602-x08_Horizontal
M3, M3#2: MountingHole_3.2mm_M3
R1: 330; R_0805_2012Metric_Pad1.20x1.40mm_HandSolder
SCL: SCL; PinHeader_1x01_P2.54mm_Vertical
SDA: SDA; PinHeader_1x01_P2.54mm_Vertical
U3: AP7361C-33E; SOT-223-3_TabPin2

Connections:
/3V3: BNO.JP1_1 (VIN), C2.1, C3.1, C6.2, D1.2 (A), D3.2 (A), R1.1, U3.3 (VO)
/5V: C5.2, J2.7, U3.1 (VI)
/SCL: BNO.JP1_4 (SCL), D1.3 (K), J2.4, SCL.1
/SDA: BNO.JP1_5 (SDA), D3.3 (K), J2.3, SDA.1
GND: ADRESS.3 (C), BNO.JP1_3 (GND), C2.2, C3.2, C5.1, C6.1, D1.1 (K), D3.1 (K), D5.1 (K), J2.8, U3.2 (GND)
unnamed: D5.2 (A), R1.2
unnamed: ADRESS.1 (A), BNO.JP1_2 (3VO)
unnamed: ADRESS.2 (B), BNO.JP2_5 (DI)

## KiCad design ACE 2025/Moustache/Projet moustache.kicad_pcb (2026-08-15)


Board: 2 copper layers, 9 parts (0 on the bottom side), 8 nets.

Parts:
BNOF: RJ45; RJ45_Amphenol_54602-x08_Horizontal
BNOT: RJ45; RJ45_Amphenol_54602-x08_Horizontal
EXT1, EXT2: RJ45; RJ45_Amphenol_54602-x08_Horizontal
H1, H2: MountingHole; MountingHole_3.2mm_M3
INPUT: RJ45; RJ45_Amphenol_54602-x08_Horizontal
MOTG: RJ45; RJ45_Amphenol_54602-x08_Horizontal
MOTH: RJ45; RJ45_Amphenol_54602-x08_Horizontal

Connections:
+5V: BNOF.7, BNOT.7, EXT1.7, EXT2.7, INPUT.7, MOTG.7, MOTH.7
/CAN+: BNOF.1, BNOT.1, EXT1.1, EXT2.1, INPUT.1, MOTG.1, MOTH.1
/CAN-: BNOF.2, BNOT.2, EXT1.2, EXT2.2, INPUT.2, MOTG.2, MOTH.2
/SCL+: BNOF.3, BNOT.3, EXT1.3, EXT2.3, INPUT.3, MOTG.3, MOTH.3
/SCL-: BNOF.4, BNOT.4, EXT1.4, EXT2.4, INPUT.4, MOTG.4, MOTH.4
/SDA+: BNOF.5, BNOT.5, EXT1.5, EXT2.5, INPUT.5, MOTG.5, MOTH.5
/SDA-: BNOF.6, BNOT.6, EXT1.6, EXT2.6, INPUT.6, MOTG.6, MOTH.6
GND: BNOF.8, BNOT.8, EXT1.8, EXT2.8, INPUT.8, MOTG.8, MOTH.8

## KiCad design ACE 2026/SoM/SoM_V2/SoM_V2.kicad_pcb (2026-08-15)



Board: 4 copper layers, 30.0 x 46.1 mm, 51 parts (26 on the bottom side), 62 nets.

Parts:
BOOT: SW_BOOT; SW_DIP_SPSTx01_Slide_6.7x4.1mm_W6.73mm_P2.54mm_LowProfile_J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
C301, C501: 10µF; R_0805_2012Metric
C302, C304, C306, C307, C310, C502: 0.1µF; R_0805_2012Metric
C303, C305, C401, C503: 1µF; R_0805_2012Metric
C308, C309: 47pF; R_0805_2012Metric
C402: 100nF; R_0805_2012Metric
C403: 100n; C_0805_2012Metric
D303: SP0502BAJT; SOT-323_SC-70
ENABLE: SW_CHIP_EN; SW_DIP_SPSTx01_Slide_6.7x4.1mm_W6.73mm_P2.54mm_LowProfile_J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
PWR: GREEN; LED_0805_2012Metric
Q501: MBT3904DW1T1G; SOT-363_SC-70-6
R201, R307, R308: 330; R_0805_2012Metric
R301, R302, R303, R304, R309, R310, R401, R402: 1k; R_0805_2012Metric
R305, R306: 27; R_0805_2012Metric
R311, R312: 60; R_0805_2012Metric
R501, R502, R503, R504: 10k; R_0805_2012Metric
RN301: 1k; R_Array_Convex_8x0602
RX: TX; LED_0805_2012Metric
STATUS: FZ2812-5050; LED_Inolux_IN-PI554FCH_PLCC4_5.0x5.0mm_P3.2mm
TX: RX; LED_0805_2012Metric
U201: NGFF_E
U301: TCA9546APWR; TSSOP-16_4.4x5mm_P0.65mm
U302: FT231XQ; QFN-20-1EP_4x4mm_P0.5mm_EP2.5x2.5mm
U305: SN65HVD230; SOIC-8_3.9x4.9mm_P1.27mm
U401: PCA9633DP1; DFN-8-1EP_2x2mm_P0.5mm_EP0.9x1.6mm
U501: ESP32-S3-MINI-1U; ESP32-S2-MINI-1U
kibuzzard-66E094ED: G***; kibuzzard-66E094ED

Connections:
/Communication/CAN+: C307.2, D303.1 (K), R311.1, U201.71 (CAN_H_MCP2515), U305.7 (CANH)
/Communication/CAN-: C304.1, D303.2 (K), R312.2, U201.73 (CAN_L_MCP2515), U305.6 (CANL)
/Communication/D+: R306.2, U302.8 (USBDP)
/Communication/D-: R305.2, U302.9 (USBDM)
/Communication/DR+: C309.1, R306.1, U201.3 (USB_D+_FT231)
/Communication/DR-: C308.1, R305.1, U201.5 (USB_D-_FT231)
CHIP_EN: ENABLE.1, Q501.6 (C1), R504.1, U201.56 (RESET_ESP32), U501.45 (EN)
CS_1: U201.20 (CS_1), U501.15 (IO11)
CS_2: U201.21 (CS_2), U501.25 (IO21)
DEBUG+: U201.48 (USB_DEBUG_D+), U501.24 (IO20)
DEBUG-: U201.46 (USB_DEBUG_D-), U501.23 (IO19)
DTR: Q501.3 (C2), R502.1, U302.18 (~DTR)
GND: BOOT.2, C301.2, C302.2, C304.2, C305.2, C306.2, C307.1, C308.2, C309.2, C310.2, C401.2, C402.2, C403.2, C501.2, C502.2, C503.2, ENABLE.2, R201.2, R310.1, STATUS.1 (VSS), U201.1 (GND), U201.7 (GND), U201.18 (GND), U201.33 (GND), U201.38 (GND), U201.39 (GND), U201.45 (GND), U201.51 (GND), U201.55 (GND), U201.57 (GND), U201.62 (GND), U201.63 (GND), U201.69 (GND), U201.75 (GND), U301.1 (A0), U301.2 (A1), U301.8 (GND), U301.13 (A2), U302.3 (GND), U302.13 (GND), U302.21 (GND), U305.2 (GND), U401.5 (GND), U501.1 (GND), U501.2 (GND), U501.42 (GND), U501.43 (GND), U501.46 (GND), U501.47 (GND), U501.48 (GND), U501.49 (GND), U501.50 (GND), U501.51 (GND), U501.52 (GND), U501.53 (GND), U501.54 (GND), U501.55 (GND), U501.56 (GND), U501.57 (GND), U501.58 (GND), U501.59 (GND), U501.60 (GND), U501.61 (GND), U501.62 (GND), U501.63 (GND), U501.64 (GND), U501.65 (GND)
GPIO0_BOOT: BOOT.1, Q501.4 (E2), R501.1, U501.4 (IO0)
GPIO4/RXD: R309.1, U501.8 (IO4)
GPIO5/TXD: R304.1, U501.9 (IO5)
GPIO15: U201.40 (GPIO15), U501.19 (IO15)
GPIO16: U201.41 (GPIO16), U501.20 (IO16)
GPIO17_U1_TXD: U201.22 (UART_TX), U501.21 (IO17)
GPIO18_U1_RXD: U201.32 (UART_RX), U501.22 (IO18)
GPIO26: U201.42 (GPIO26), U501.26 (IO26)
GPIO33: U201.43 (GPIO33), U501.28 (IO33)
GPIO34: U201.44 (GPIO34), U501.29 (IO34)
GPIO38_ADDRESSABLE_LED: STATUS.2 (DIN), U201.6 (GPIO38&LED), U501.34 (IO38)
GPIO45: U201.52 (GPIO45), U501.41 (IO45)
GPIO46: U201.53 (GPIO46), U501.44 (IO46)
GPIO48/CAN_INT: U201.36 (GPIO48), U501.30 (IO48)
I2C_SCL_0_TCA: RN301.2 (R2.1), U201.11 (I2C_SCL_1_TCA), U301.5 (SC0)
I2C_SCL_1_TCA: RN301.4 (R4.1), U201.15 (I2C_SCL_2_TCA), U301.7 (SC1)
I2C_SCL_2_TCA: RN301.6 (R6.1), U201.16 (I2C_SCL_3_TCA), U301.10 (SC2)
I2C_SCL_3_TCA: RN301.8 (R8.1), U201.19 (I2C_SCL_4_TCA), U301.12 (SC3)
I2C_SCL_ESP32: R302.2, R402.2, U201.60 (I2C_SCL_ESP32), U301.14 (SCL), U401.6 (SCL6), U501.6 (IO2)
I2C_SDA_0_TCA: RN301.1 (R1.1), U201.9 (I2C_SDA_1_TCA), U301.4 (SD0)
I2C_SDA_1_TCA: RN301.3 (R3.1), U201.13 (I2C_SDA_2_TCA), U301.6 (SD1)
I2C_SDA_2_TCA: RN301.5 (R5.1), U201.14 (I2C_SDA_3_TCA), U301.9 (SD2)
I2C_SDA_3_TCA: RN301.7 (R7.1), U201.17 (I2C_SDA_4_TCA), U301.11 (SD3)
I2C_SDA_ESP32: R301.2, R401.2, U201.58 (I2C_SDA_ESP32), U301.15 (SDA), U401.7 (SDA), U501.5 (IO1)
I2S_BCLK: U201.8 (I2S_BCLK), U501.16 (IO12)
I2S_DIN/DOUT: U201.12 (I2S_DIN/DOUT), U501.18 (IO14)
I2S_WS: U201.10 (I2S_WS), U501.17 (IO13)
unnamed: PWR.1 (K), R201.1
unnamed: R307.1, RX.2 (A)
unnamed: R308.1, TX.2 (A)
unnamed: C303.2, D303.3 (A)
unnamed: Q501.2 (B1), R502.2
unnamed: Q501.5 (B2), R503.2
unnamed: U201.64 (PWM_1_PCA), U401.1 (PWM1)
unnamed: U201.66 (PWM_2_PCA), U401.2 (PWM2)
unnamed: U201.68 (PWM_3_PCA), U401.3 (PWM3)
unnamed: U201.70 (PWM_4_PCA), U401.4 (PWM4)
unnamed: R304.2, U305.1 (D)
unnamed: R309.2, U305.4 (R)
unnamed: R310.2, U305.8 (Rs)
RESET_OTHERS: R303.2, U201.54 (RESET_AUTRES), U301.3 (RESET_N), U501.27 (IO47)
RTS: Q501.1 (E1), R503.1, U302.19 (~RTS)
SPI_CLK_ESP32: U201.23 (SPI_CLK), U501.10 (IO6)
SPI_MISO_ESP32: U201.37 (SPI_MISO), U501.12 (IO8)
SPI_MOSI_ESP32: U201.35 (SPI_MOSI), U501.11 (IO7)
U0RXD: RX.1 (K), U302.17 (TXD), U501.40 (RXD0)
U0TXD: TX.1 (K), U302.1 (RXD), U501.39 (TXD0)
Vcc_3V3: C301.1, C302.1, C305.1, C306.1, C310.1, C401.1, C402.1, C403.1, C501.1, C502.1, C503.1, PWR.2 (A), R301.1, R302.1, R303.1, R307.2, R308.2, R401.1, R402.1, R501.2, R504.2, RN301.9 (R8.2), RN301.10 (R7.2), RN301.11 (R6.2), RN301.12 (R5.2), RN301.13 (R4.2), RN301.14 (R3.2), RN301.15 (R2.2), RN301.16 (R1.2), STATUS.3 (VDD), U201.2 (Vcc_3v3), U201.4 (Vcc_3v3), U201.72 (Vcc_3v3), U201.74 (Vcc_3v3), U301.16 (VCC), U302.10 (3V3OUT), U302.11 (~RESET), U302.12 (VCC), U302.20 (VCCIO), U305.3 (VCC), U401.8 (VCC), U501.3 (3V3)
Vref_CAN: C303.1, R311.2, R312.1, U305.5 (Vref)

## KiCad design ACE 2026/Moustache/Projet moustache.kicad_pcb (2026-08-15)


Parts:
C202, C204: 4,7µF; C_0805_2012Metric_Pad1.18x1.45mm_HandSolder
D201: Green_power; D_0805_2012Metric
H1, H2: MountingHole; MountingHole_3.2mm_M3
J1, J2, J3, J4, J5, J6, J7: RJ45; RJ45_Amphenol_54602-x08_Horizontal
R203: 330; R_0805_2012Metric_Pad1.20x1.40mm_HandSolder
R701, R704: 1k; R_0805_2012Metric_Pad1.20x1.40mm_HandSolder
TP201: TP_GND_IN; TestPoint_Pad_4.0x4.0mm
TP203: TP_3v3; TestPoint_Pad_D4.0mm
TP204: TP_5V; TestPoint_Pad_D4.0mm
U201: AP7361C-33E; SOT-223-3_TabPin2

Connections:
/CAN+: J1.1, J2.1, J3.1, J4.1, J5.1, J6.1, J7.1
/CAN-: J1.2, J2.2, J3.2, J4.2, J5.2, J6.2, J7.2
/EXTRA_1: J1.5, J2.5, J3.5, J4.5, J5.5, J6.5, J7.5
/EXTRA_2: J1.6, J2.6, J3.6, J4.6, J5.6, J6.6, J7.6
/SCL: J1.4, J2.4, J3.4, J4.4, J5.4, J6.4, J7.4, R704.2
/SDA: J1.3, J2.3, J3.3, J4.3, J5.3, J6.3, J7.3, R701.2
GND: C202.1, C204.1, D201.1 (K), J1.8, J2.8, J3.8, J4.8, J5.8, J6.8, J7.8, TP201.1, U201.2 (GND)
unnamed: D201.2 (A), R203.2
Vcc_3V3: C204.2, R203.1, R701.1, R704.1, TP203.1, U201.3 (VO)
Vcc_5V: C202.2, J1.7, J2.7, J3.7, J4.7, J5.7, J6.7, J7.7, TP204.1, U201.1 (VI)


Board: 2 copper layers, 113.5 x 52.9 mm, 19 parts (0 on the bottom side), 10 nets.

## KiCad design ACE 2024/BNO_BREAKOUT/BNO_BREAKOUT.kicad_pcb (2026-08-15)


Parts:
C1: 4.7uF; C_1812_4532Metric_Pad1.57x3.40mm_HandSolder
C2, C3, C4: 1n; C_1812_4532Metric_Pad1.57x3.40mm_HandSolder
D1, D2, D3: BAV99; SOT-23
D4: D_TVS_Filled
J1: Conn_02x04_Counter_Clockwise; Molex_Nano-Fit_105314-xx08_2x04_P2.50mm_Horizontal
SW1: SW_SPDT; SW_SPDT_CK_JS102011SAQN
U1: 4754; MODULE_4754; PARTREV 2021-03-16

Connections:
/3V3: C1.1, C2.1, C3.1, C4.1, D1.2 (A), D2.2 (A), D3.2 (A), D4.2 (A2), J1.1, U1.JP1_1 (VIN)
/RST: D2.3 (K), J1.8, U1.JP2_4 (~RST)
/SCL: D1.3 (K), J1.3, U1.JP1_4 (SCL)
/SDA: D3.3 (K), J1.6, U1.JP1_5 (SDA)
GND: C1.2, C2.2, C3.2, C4.2, D1.1 (K), D2.1 (K), D3.1 (K), D4.1 (A1), J1.2, J1.4, J1.5, J1.7, SW1.3 (C), U1.JP1_3 (GND), U1.P1, U1.P2, U1.P3, U1.P4
unnamed: SW1.1 (A), U1.JP1_2 (3VO)
unnamed: SW1.2 (B), U1.JP2_5 (DI)

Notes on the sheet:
Power protection circuit
Data integrity
Static shock


Board: 2 copper layers, 31.4 x 49.0 mm, 11 parts (0 on the bottom side), 7 nets.

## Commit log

2026-06-23 Initial commit for the BIMU
    [Alimentation.kicad_sch, BIMU_V_1.kicad_pcb, BIMU_V_1.kicad_sch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]
2026-06-24 Avancement of different part of the schematic
    Add and reorganize numerous symbol definitions and annotations in Alimentation.kicad_sch: new TestPoint, LED, R_US/Resistor symbols, BAV99 diode, MountingHole, AP7361C-33E regulator, power/GND symbol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
    [Alimentation.kicad_sch, BIMU_V_1.kicad_pcb, BIMU_V_1.kicad_sch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]
2026-07-16 finalisation des connexions pour le BIMU. Il reste encore une révision à faire
    [Alimentation.kicad_sch, Capteur.kicad_sch, Controle.kicad_sch]
2026-07-18 Finalisé la révision du schéma
    [Alimentation.kicad_sch, BIMU_V_1.csv, Capteur.kicad_sch]
2026-07-19 Réglé les problèmes soulevé par la pull request
    [Alimentation.kicad_sch, Capteur.kicad_sch, Controle.kicad_sch]
2026-07-19 Réglé des petits problèmes avec la puce IMU
    [Capteur.kicad_sch, Controle.kicad_sch]
2026-07-19 mise à jours de numéro de composants
    [BIMU_V_1.csv, BIMU_V_1.kicad_pcb, Controle.kicad_sch]
2026-07-23 Avancement du pcb layout
    [Alimentation.kicad_sch, BIMU_V_1.csv, BIMU_V_1.kicad_pcb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]
2026-08-08 Avancement placement des composants
    [BIMU_V_1.kicad_pcb]
2026-08-08 Finaliser le placement des composants et routé le CAN différentiel
    [BIMU_V_1.csv, BIMU_V_1.kicad_pcb]
2026-08-08 Avancement de la puissance
    [BIMU_V_1.kicad_pcb, freerouting.dsn, temp-freerouting.dsn]
2026-08-09 Electrical schematic ready for first PR
    [Alimentation.kicad_sch, Controle.kicad_sch, daisyChainPcb_V1_0.kicad_pcb]
2026-08-09 Forgot datasheet for 5V to 3V chip
    [Alimentation.kicad_sch]
2026-08-09 Traceage des pistes du PCB bientot complété
    [BIMU_V_1.kicad_pcb, freerouting.dsn, temp-freerouting.dsn]
2026-08-11 Schematic PR fix - Separated schematic sections into blocs - Indicated the connector type in the name - Added datasheets for the connectors
    [Controle.kicad_sch]
2026-08-12 Added datasheet for the RJ45 connectors
    [Controle.kicad_sch]
2026-08-12 Updated grounds to reflect the two grounds we have
    [Alimentation.kicad_sch, Controle.kicad_sch]
2026-08-15 Rajouter les anciennes versions des PCB
    [691137710002.step, Alimentation.kicad_sch, Analogue.kicad_sch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]
2026-08-15 Amélioration silkscreen
    [BIMU_V_1.kicad_pcb]
2026-08-15 Finalisation du Silkscreen
    [BIMU_V_1.kicad_pcb]
2026-08-16 Amélioration de la documentation
    [BIMU_V_1.kicad_pcb]
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2026-08-19 Légère amélioration de la clarité des shémas électriquea
    [Controle.kicad_sch]
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2026-08-19 Fix typos and enhance PCB design recommendations
    Corrected spelling and grammatical errors in the PCB guide. Added additional recommendations for component placement and track routing.
2026-08-19 Très légères modifications
    [BIMU_V_1.kicad_pcb]
2026-08-19 Rajouté un dossier ressource pour avoir les images et un template pour commencé les PCB
    [Alimentation.kicad_sch, Capteur.kicad_sch, Controle.kicad_sch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]
2026-08-19 refaire la bonne structure
    [Alimentation.kicad_sch, Capteur.kicad_sch, Controle.kicad_sch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]
2026-08-19 Fixer la structure pour quelle corresponde à ce qui est voulu
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2026-08-19 Creation des fichiers de production
    [BIMU_V_1.csv, bom.csv, designators.csv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]
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2026-08-20 Fixer le problème de footprint avec le BIMU!
    [BIMU_V_1.kicad_pcb, Controle.kicad_sch]
2026-08-21 Changé pour de vrai le footprint
    [BIMU_V_1.kicad_pcb]
2026-08-21 Change la footprint de D201 de 'digikey-footprints:SOT23-6L' à 'BIMU:SOT23-6L
    [BIMU_V_1.kicad_pcb]
2026-08-22 Fixer les numéro de composant
    [Alimentation.kicad_sch, Controle.kicad_sch, daisyChainPcb_V1_0.kicad_sch]
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2026-08-22 conversion de version de kicad
    [Alimentation.kicad_sch, BIMU_V_1.kicad_sch, Capteur.kicad_sch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]
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2026-08-26 Added motor cutout graphic with the screw holes
    [motorCutoutWithScrewHoles.dxf]
2026-08-26 Added new cutout
    [Alimentation.kicad_sch, daisyChainPcb_V1_0.kicad_pcb, daisyChainPcb_V1_0.kicad_sch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]
2026-08-28 Saving before trying a new layout
    [Alimentation.kicad_sch, Capteur.kicad_sch, Controle.kicad_sch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]
2026-08-28 Ready for PCB PR
    [Controle.kicad_sch, daisyChainPcb_V1_0.kicad_pcb]
2026-08-29 amélioration de la forme du pcb
    [PCB_OUTLINE.dxf, daisyChainPcb_V1_0.kicad_pcb]
2026-08-29 Version optimisé du PCB
    [PCB_OUTLINE.dxf, daisyChainPcb_V1_0.kicad_pcb]
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2026-08-30 Finished routing the pcb I want to clean up the silkscreen before saying it is finished
    [daisyChainPcb_V1_0.kicad_pcb]
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2026-08-31 Trying to fix the branch
    [daisyChainPcb_V1_0.kicad_pcb]
2026-08-31 Réglé le placement de certain silkscreen et les vias du stiching
    [daisyChainPcb_V1_0.kicad_pcb]
2026-08-31 Halfway through better placing the TP
    [daisyChainPcb_V1_0.kicad_pcb]
2026-09-01 Check up vite fait
    [daisyChainPcb_V1_0.kicad_pcb]
2026-09-01 Fixé les règles de PCB
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2026-09-01 Correction inversion usb pin
    [BIMU_V_1.kicad_pcb, Controle.kicad_sch]
2026-09-02 Changed placement of TPs and size of vias for stitching
    [daisyChainPcb_V1_0.kicad_pcb]
2026-09-02 Corrected some DRC warnings and errors
    [daisyChainPcb_V1_0.kicad_pcb]
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2026-09-04 Auto stash before merge of "main" and "origin/main"
    [BIMU_V_1.csv, Controle.kicad_sch, bom.csv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]
2026-09-15 Added 3d model for ethernet port and XT30 connector
    [Port ethernet.step, XT30PW-M.step, daisyChainPcb_V1_0.kicad_pcb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]
2026-09-21 Update .history, BIMU_V_1.kicad_prl, BIMU_V_1.kicad_pro, and 14 more files
    [Alimentation.kicad_sch, BIMU_V_1.kicad_pcb, BIMU_V_1.kicad_sch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]
2026-09-21 Réglé le problème dans le shémas électrique
    [Alimentation.kicad_sch, BIMU_V_1_1.csv, BIMU_V_1_1.kicad_pcb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]
2026-09-21 Fixer le PCB
    [BIMU_V_1_1.kicad_pcb]
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2026-09-23 Rajouté une switch demandé par Éloi
    [BIMU_V_1_1.kicad_pcb, Controle.kicad_sch]
2026-09-25 Fixer les erreurs commise avec le CAN
    [BIMU_V_1_1.kicad_pcb, Controle.kicad_sch]
2026-09-29 Rajout de Diode pour protégé le USB et la batterie(par short ensemble)
    [Alimentation.kicad_sch, Controle.kicad_sch]
2026-10-01 Faire les modifications requise pour le pcb
    [Alimentation.kicad_sch, BIMU_V_1_1.kicad_pcb]
2026-10-01 Finalisation de la mise à jour du BIMU
    [BIMU_V_1_1.kicad_pcb]
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
